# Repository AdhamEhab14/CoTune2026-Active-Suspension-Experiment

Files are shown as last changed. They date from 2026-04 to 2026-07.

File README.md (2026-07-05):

# CoTune Remote Control Lab

A remote-access control systems laboratory built as a graduation project at the Faculty of Engineering, Ain Shams University (Mechatronics Program). CoTune lets a student log in from anywhere, join a queue, tune a real LQR controller, run it on physical hardware over the internet, and watch the result live — combining a mechanical testbed, an embedded real-time controller, and a cloud/web platform into one system.

**Live demo video:** https://www.youtube.com/watch?v=JONjcuDR5eo
**Live platform:** https://main.d35sofljaoe99e.amplifyapp.com/
**Full thesis (PDF):** [`docs/CoTune_Thesis.pdf`](docs/CoTune_Thesis.pdf)

## What's in this repo

This repo brings together the three parts of the CoTune graduation project:

| Folder | What it is |
|---|---|
| [`active-suspension/`](active-suspension/) | Mechanical design, system identification, LQR control, and ESP32/FreeRTOS firmware for the quarter-car active suspension rig. |
| [`rotary-pendulum/`](rotary-pendulum/) | Git submodule pointing to the standalone [Rotary-Inverted-Pendulum](https://github.com/AdhamEhab14/Rotary-Inverted-Pendulum) repo — the Furuta pendulum swing-up + LQR experiment. Kept as its own repo since it also works as a standalone project. |
| [`web-cloud/`](web-cloud/) | The React + AWS front end and cloud infrastructure (IoT Core, Cognito, DynamoDB, Amplify) that puts both experiments online. Built with the team; included here as a snapshot of the work. |
| [`docs/CoTune_Thesis.pdf`](docs/CoTune_Thesis.pdf) | The full graduation thesis this project is based on. |

## Project overview

Traditional control labs are bound by physical presence, fixed schedules, and limited hardware access. CoTune addresses that by exposing two laboratory-scale experiments — an **active suspension system** and a **rotary inverted pendulum** — through a browser-based platform that streams live telemetry and video, and lets students push real control parameters to real hardware.

### 1. Active Suspension

A bench-scale quarter-car rig (sprung mass / unsprung mass / road input, each a plate on linear guides) actuated by a capstan-driven and a lead-screw-driven 775 DC motor.

- **Model:** 2-DOF quarter-car, state vector `[suspension travel, sprung velocity, tire deflection, unsprung velocity]`.
- **System ID:** grey-box estimation of motor and mechanical parameters (`Ks = 900 N/m`, `Bs = 58.08 N·s/m`, `Kus = 1250 N/m`, `Bus = 14.73 N·s/m`) via MATLAB Parameter Estimator, validated in closed loop.
- **Control:** Linear Quadratic Regulator (LQR), gains solved from the Riccati equation, running against a discrete Kalman filter that fuses VL53L0X ToF distance sensors with MPU6050 IMUs.
- **Embedded:** multi-rate FreeRTOS on an ESP32 (500 Hz IMU/control loop, 50 Hz ToF loop), custom C++ S-Function for sensor/Kalman-filter handling, I²C mutex + bus-recovery logic, cascaded alpha/high-pass/low-pass filtering before the control law, PWM/direction output to a Cytron motor driver, and hardware limit-switch safety cutoffs.

### 2. Rotary Inverted Pendulum (standalone submodule)

A Furuta pendulum: a horizontal rotary arm (actuated) balancing a free-swinging vertical pendulum link (unactuated) — a classic underactuated, nonlinear benchmark.

- Nonlinear Euler-Lagrange dynamics, linearized about the upright equilibrium for LQR design.
- Two-stage system identification (motor first, then coupled arm-pendulum dynamics).
- Hybrid embedded controller: energy-based swing-up until the pendulum nears upright, then an automatic switch to LQR stabilization — all running on the same ESP32/FreeRTOS architecture as the suspension rig.
- Lives in its own repo ([Rotary-Inverted-Pendulum](https://github.com/AdhamEhab14/Rotary-Inverted-Pendulum)) and is linked here as a submodule so it can be browsed as part of CoTune as a whole, or used completely on its own.

### 3. Web & Cloud Platform

Turns both rigs into a remote lab, accessible from any browser:

- **Hardware tier:** ESP32 boards run the control loop locally and act as MQTT clients (mutual TLS) to AWS IoT Core.
- **Cloud tier:** AWS IoT Core (MQTT broker), Amazon Cognito (auth), DynamoDB (queue state + session/LQR parameter logging), AWS Amplify (hosting + CI/CD).
- **Client tier:** a modular React SPA — in-browser LQR solver, live Chart.js telemetry, a Twitch-embedded live camera feed, per-experiment access queues with timed sessions, URDF-based 3D pre-experiment simulations, and a Groq/Llama-powered AI assistant scoped to control-theory Q&A.
- MQTT topics separate commands from telemetry per experiment (`SUSP/Parameters` / `suspension/telemetry` at 1 Hz, `ROTARY/Parameters` / `rotary/telemetry` at 10 Hz), QoS 0, JSON payloads under 256 bytes.

### 4. Digital Twin (Active Suspension)

An offline, post-session **seven-state Augmented Extended Kalman Filter (AEKF)** that re-estimates the suspension's real spring stiffness and damping from downloaded session telemetry (augmenting the 4-state model with `Ks`, `Bs`, and a road-phase offset). On a real 140s session it converged to `Ks ≈ 936 N/m` (+4% vs. nominal) and `Bs ≈ 41.2 N·s/m` (-29% vs. nominal), and closed-loop validation against the real data cut amplitude error from 8.2% (nominal model) to 3.1% (AEKF model) — while also surfacing an unmodeled ~1.8 Hz structural resonance in the physical rig. Full derivation and results are in Chapter 6 of the thesis.

## Tech stack

**Mechanical/Electrical:** SolidWorks, Simscape Multibody, 775 DC motors, Cytron motor drivers, VL53L0X ToF sensors, MPU6050 IMUs, incremental encoders.
**Embedded:** ESP32, FreeRTOS, Simulink Support Package for Arduino, custom C++ S-Functions, discrete Kalman filtering.
**Control:** MATLAB/Simulink, LQR, Algebraic Riccati Equation solving, grey-box system identification.
**Cloud/Web:** React 18, AWS Amplify, AWS IoT Core (MQTT), Amazon Cognito, DynamoDB, Chart.js, Three.js/@react-three/fiber + urdf-loader, Groq API (Llama 3.3 70B).

## Team

Graduation project, Mechatronics Engineering Program, Faculty of Engineering – Ain Shams University (2025–2026), supervised by **Dr. Mohamed Omar**.

Adham Ehab Saleh · Abdelrahman Hany Abdelrahman · Ahmed Mohamed Ramadan · Ahmed Yasser Hosny · Khalid Amin Abdullah · Omar Mohamed Fathy

## License

MIT — see [`LICENSE`](LICENSE).

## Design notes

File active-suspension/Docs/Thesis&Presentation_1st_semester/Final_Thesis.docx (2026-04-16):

CoTune Active Suspension & Rotary Inverted Pendulum Submitted By: Adham Ehab Saleh Abdelrahman Hany Abdelrahman Ahmed Mohamed Ramadan Ahmed Yasser Hosny Khalid Amin Abdullah Omar Mohamed Fathy | . Mechatronics Program Graduation Project Report Supervisor: Dr. Mohamed Omar 28/1/2026

DECLARATION

We hereby certify that this Project submitted as part of our partial fulfilment of BSc in Mechatronics Engineering is entirely our own work, that we have exercised reasonable care to ensure its originality, and does not to the best of our knowledge breach any copyrighted materials, and have not been taken from the work of others and to the extent that such work has been cited and acknowledged within the text of our work.

Signed: by

Adham Ehab Saleh Mokhtar
Abdelrahman Hany Abdelrahman Omar
Ahmed Mohamed Ramadan
Ahmed Yasser Hosny
Khaled Amin
Omar Mohamed Fathy Ibrahim

Date: 28th of January 2026

ACKNOWLEDGMENT

We would like to express our sincere gratitude to our supervisor,
Dr. Mohamed Omar, for his guidance and continuous support throughout this project.

Abstract

This thesis focuses on the development of new experimental platforms intended to extend the capabilities of the CoTune Control Laboratory, with the aim of enhancing hands-on learning in control systems education through real-hardware experimentation. The project introduces two laboratory-scale experiments—an active suspension system and a rotary inverted pendulum—designed to complement theoretical coursework with practical implementation and experimental validation.

Both experimental setups were developed from the ground up, starting with mechanical design and hardware integration, followed by system modeling and real-time experimental operation. The platforms are designed to support remote and flexible experimentation, allowing users to configure parameters and observe system behavior through live visual feedback, without requiring physical presence in the laboratory.

The active suspension experiment represents a quarter-car model and enables the study of vertical vehicle dynamics, disturbance effects, and suspension performance using a compact laboratory-scale setup. The rotary inverted pendulum experiment represents a classical unstable system and serves as a benchmark platform for studying nonlinear dynamics, instability, and real-time feedback control.

Together, these experimental platforms expand the range of control problems addressed within the CoTune Laboratory and provide a foundation for future integration into remote-access educational environments, supporting a closer connection between control theory and practical implementation.

Table of Contents

List of Figures

List of Tables

# 1. Introduction

## 1.1. Background

Traditional control laboratories are a core component of engineering education, and most engineering students gain some level of hands-on experience during their studies. However, these laboratories are typically constrained by physical presence, fixed schedules, limited hardware availability, and restricted experiment time. As a result, students are often unable to freely test control theories, explore parameter variations, or repeat experiments outside scheduled lab sessions.

In addition, increasing student numbers and limited laboratory resources make it difficult to provide equal experimental access to all students. These constraints reduce the effectiveness of laboratory-based learning, particularly in control engineering, where repeated experimentation and real-time observation are essential for developing intuition and practical understanding.

The primary limitation addressed in this work is not the absence of control laboratories, but rather the lack of remote, flexible, and continuously accessible experimental platforms that allow students to interact with real hardware without being physically present in the laboratory.

## 1.2. CoTune Laboratory Concept

The Cotune Control Laboratory was developed to overcome the limitations of conventional control labs by enabling remote experimentation on real physical systems. CoTune allows students to access laboratory experiments through an online platform, configure system and controller parameters, and observe real-time system behavior without requiring physical presence in the lab.

Instead of replacing traditional laboratories, CoTune extends their functionality by decoupling experimentation from location and time constraints. This approach allows students to test control theories, analyze system responses, and validate design choices using real hardware, while maintaining the realism and non-ideal behavior of physical systems.

The CoTune Laboratory is designed as a unified framework that integrated multiple experimental platforms, real-time control execution, live data acquisition, and visual feedback, providing consistent user experience across different experiments.

## 1.3. Remote Experimentation and Live Interaction Framework

A core feature of the Cotune Laboratory is the ability to perform experiments remotely without requiring physical presence in the lab. This capability allows students to interact with real experimental setups through an online platform, overcoming common limitations related to lab availability, scheduling, and physical access.

Using the CoTune web interface, students can select an experiment, set the relevant parameters, and run the experiment directly on the physical hardware. The system executes the experiment in real time, while measured signals and system responses are streamed back to the user. In parallel, a live camera feed provides continuous visual feedback, allowing students to observe the physical motion of the system as the experiment is running.

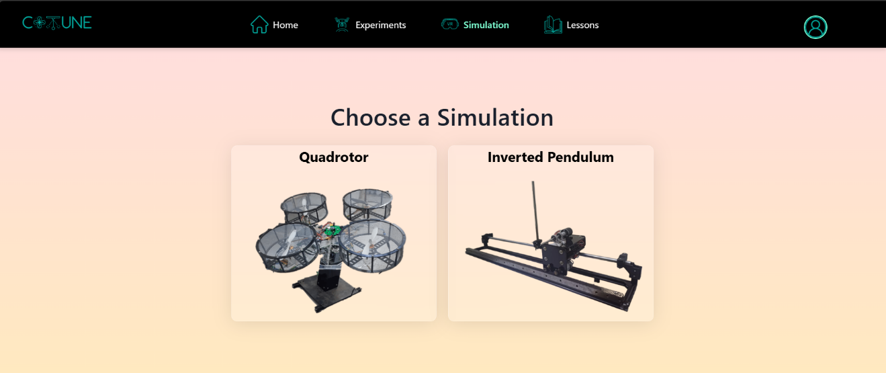
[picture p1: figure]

This interaction model preserves the essential characteristics of hands-on experimentation, including real-time dynamics and non-ideal behavior, while enabling experiments to be performed from any location. Screenshots of the web interface and live camera feed are included to illustrate the structure of the platform and the user interaction flow.

Figure 1.CoTune web Interface

## 1.4. Existing Experimental Platforms

Before the work presented in this thesis, the CoTune Laboratory already included several experimental platforms designed to cover a range of control applications. These platforms include:

- A quadrotor system.
- A linear inverted pendulum
- A ball balancing setup.
- A robotic arm.
- A three-dimensional scanning system.

Each of these experiments addresses different aspects of control systems, such as stability, multivariable control, motion control, and sensor-based feedback. Together, they form a solid foundation for practical control education within the CoTune framework. However, the existing platforms did not fully cover certain important control problems related to disturbance rejection and classical benchmark systems, motivating the addition of new experiments.

## 1.5. Motivation for the Newly Added Experiments

The selection of the active suspension and the rotary inverted pendulum was driven by the need to expand the range of control problems accessible through the CoTune Laboratory. The focus was not on adding more experiments for volume, but on introducing systems that offer clear educational value and complement the existing setups.

Relevance to vehicle dynamics and suitability for studying disturbance effects and performance trade-offs in controlled mechanical systems motivated the choice of the active suspension system. It allows students to directly observe how control actions influence system response under external excitations, making it well suited for both conceptual understanding and practical testing.

Considered a classical unstable system widely used in control education, the rotary inverted pendulum was selected for its ability to clearly demonstrate instability and real-time stabilization. Its dynamics offer an effective platform for testing control strategies under challenging conditions.

Together, these two experiments extend the laboratory’s coverage while fitting naturally within the existing CoTune framework.

# 2. Active Suspension Experiment

## 2.1. Introduction

### 2.1.1. Background

The automotive industry is currently undergoing a significant transformation driven by advances in control systems, electronics and embedded software. Modern vehicles are no longer purely mechanical systems; instead, they are increasingly becoming more complex cyber-physical systems. This evolution has led to higher expectations from passengers, who now demand not only reliable transportation, but also enhanced ride comfort, safety, and overall driving experience.

Among the vehicle subsystems, the suspension system plays a crucial role in isolating the vehicle body from road disturbance while ensuring stable vehicle behavior. Traditional passive suspension systems are limited by fixed mechanical properties that prevent adaptation to varying road conditions. These limitations have motivated the development of advanced suspension technologies that integrate control algorithms with mechanical design.

### 2.1.2. Suspension System

The suspension system is a fundamental subsystem in any road vehicle, responsible for supporting the vehicle weight, isolating the vehicle body from road disturbances, and ensuring stable vehicle behavior during motion by maintaining the traction force between the tire and the road surface.

A typical suspension system consists of mechanical elements such as springs, dampers, and linkages. The springs support the vehicle load and absorb energy from road irregularities, while the dampers dissipate this energy to limit excessive oscillations. Together, these components transfer forces between the vehicle body and the road surface while reducing the unwanted vibrations.

Conventional suspension systems require a compromise between ride comfort and road handling. Improving one usually leads to reduction in the other, which limits the overall system performance.

### 2.1.3. Passive Suspension

Passive suspension is the traditional suspension configuration used in most conventional vehicles. The dynamic behavior of a passive suspension system is entirely determined by the fixed mechanical properties of these components.

Due to the fixed nature of passive suspension parameters, these systems are unable to adapt to changing road conditions or driving situations.

### 2.1.4. Active Suspension

The limitations of the passive suspension have motivated the development of active suspension technology. Addressing this limitation through the integration of mechanical components, sensors, actuators and control algorithms. This actuator can apply controlled forces between the vehicle body and the wheel assembly based on sensor measurements and control commands. Now the system can respond to road disturbance in real time rather than relying solely on passive energy dissipation.

### 2.1.5. Classification of Active Suspension

There are 2 main classes of active suspension

- Semi-Active Suspension

The active element is embedded within the damper to vary the damping coefficient. This is achieved by varying the diameter of an orifice or applying magnetic field to small magnetic particles suspended within the hydraulic fluid in the damper. They are still limited because they can only dissipate energy; they cannot generate an independent force to lift the body or push the wheel down

- Full-Active Suspension

The active element is separate and parallel to the damper to producing force. Such element can be a linear motor or a hydraulic cylinder.

Figure 2. Suspension Types

### 2.1.6. Comparison between Active and Semi-Active Suspension

While Full-Active suspension offers superior performance, the high complexity and large power consumption are obstacles to their adoption into everyday vehicles keeping them as high-end feature offered only in luxury vehicles.

Semi-Active Suspension offers good compromise. Because it has better performance compared to passive systems, and low energy consumption and its simplicity compared to Full-Active suspension made it a more popular option that can be adopted into more vehicles.

### 2.1.7. Problem Statement for Active Suspension

Although active suspension systems are widely used in modern automotive engineering, their practical implementation is rarely emphasized in undergraduate education. Advanced control techniques such as the Linear Quadratic Regulator (LQR) are often studied through simulations, which assume ideal operating conditions and do not capture real-world effects such as friction, actuator limitations, and sensor noise.

As a result, students often struggle to translate theoretical control designs into reliable behavior when applied to real hardware. This challenge is further compounded by the fact that existing active suspension experimental platforms are typically expensive and limited in availability, which restricts meaningful hands-on experience.

This project addresses these limitations by developing a laboratory-scale active suspension experiment that is accessible, cost-effective, and suitable for remote operations. The proposed platform enables the practical validation of control strategies on real hardware while allowing students to directly observe the impact of physical constraints and non-ideal system dynamic.

## 2.2. Mechanical System

### 2.2.1. Overall Mechanical Architecture

The active suspension system is implemented as a bench-scale mechanical representation of a quarter-car model, designed to capture the essential vertical dynamics of a vehicle suspension while maintaining experimental flexibility. Our Mechanical Architecture is inspired by widely used educational active suspension platforms, particularly the Quanser active suspension experiment, which serves as a reference benchmark in control education.

The developed system adopts a vertically stacked, three-mass configuration, where each mass is constrained to move along a single vertical axis. This configuration allows the suspension dynamics to be studied in a simplified yet physically meaningful form, while remaining suitable for laboratory-scale implementation and remote experimentation.

The mechanical structure consists of three rigid plates arranged vertically:

1. Top acrylic plate (sprung mass): represents the vehicle body
2. Middle acrylic plate (unsprung mass): represents the wheel-tire assembly
3. Bottom plate (road input): represents the road surface excitation

Each plate is guided by parallel vertical shafts and supported by linear bearing blocks, ensuring that motion is strictly translated along the vertical axis with negligible lateral displacement

This arrangement allows the system to physically emulate the classical quarter-car suspension model, where:

- Relative displacement between the top and middle plates corresponds to suspension travel
- Relative displacement between the middle and bottom corresponds to tire deflection

### 2.2.2. Actuation system

The actuation system is responsible for actively injecting energy into the suspension mechanism to regulate the vertical motion of the masses and counteract road-induced disturbances. In contrast to passive suspension elements, the actuator enables direct control over the system dynamics.

#### 2.2.2.1. Actuator Type and Placement

A brushed DC motor of type 775 is employed as the active actuator in the suspension system. This motor type was selected due to its high rotational speed, compact form factor, availability, and suitability for laboratory-scale experiments. In an active suspension system, the actuator must react within milliseconds to road bumps. The 775 motor provides the necessary "bandwidth" (speed) to move the plates quickly.

Figure 3. 775 DC motor

Motor Type | Operating Voltage | Nominal Voltage | No-Load Speed | Rated Current | Stall Torque | Weight
775 DC Motor | 6–20 VDC | 12 VDC | 12,000 RPM at 12 V | 1.2 A at 12 V | 79 N.cm at 14.4 V | 350 g

Table 1. 775 DC Motor Specifications

#### 2.2.2.2. Suspension Motor Placement

The actuator is mounted on a rigid bracket that is firmly attached to the top plate (sprung mass). The actuator shaft is directly connected to a pulley, which transfers the motor motion through a belt transmission system with a reduction ratio of 2:1. The second pulley is mounted on a horizontal shaft supported by bearings. Through this configuration, the motor primarily influences the relative motion between the vehicle body (sprung mass) and the wheel assembly (unsprung mass), enabling active regulation of suspension travel and body motion.

Figure 4. Suspension Motor Fixation

#### 2.2.2.3. Road-Excitation Motor Placement

The road excitation motor is mounted on a rigid bracket that is firmly fixed to the base of the system, which serves as the stationary reference frame for the experiment. The motor shaft is connected to a pulley that drives a belt transmission system with a reduction ratio of 2:1. The driven pulley is mounted directly on the lead screw, converting the motor’s rotational motion into linear vertical displacement of the bottom plate. Through this configuration, the motor generates controlled vertical motion of the road input, allowing different excitation profiles to be applied to the suspension system. This arrangement ensures that road disturbances are introduced independently of the suspension actuation, providing a clear and repeatable means of exciting the system for experimental analysis.

Figure 5. Road Excitation Motor Fixation

### 2.2.3. Mechanical Transmission

#### 2.2.3.1. Lead Screw Mechanism for Road Excitation

A lead screw transmission is employed to generate the vertical displacement that represents road excitation. In this mechanism, motor rotation is converted into precise linear motion through a Leadscrew and nut assembly with pitch 8mm per revolution, resulting in a well-defined and repeatable vertical displacement of the base plate.

The lead screw was selected for this function due to its high positional accuracy, mechanical stiffness, and repeatability, which are essential for generating deterministic disturbance profiles such as steps, ramps, or sinusoidal inputs. Ensuring that the imposed input is known and independent of the suspension response.

Figure 6. Lead Screw Mechanism

#### 2.2.3.2. Capstan Mechanism for Active Actuation

The active suspension actuator utilizes a capstan (cable–drum) transmission to convert the rotary motion of the DC motor into a bidirectional linear force applied along the suspension axis. In this configuration, motor rotation drives a cylindrical drum with radius (r = 6mm) around which a tensioned cable is wrapped and routed through guiding elements to the moving suspension plate. Rotation of the drum results in a controlled change in cable length, producing upward or downward linear actuation depending on the direction of rotation.

This mechanism was selected due to its ability to deliver smooth and continuous force transmission with minimal backlash when properly tensioned. The compliant nature of the cable transmission also allows the actuator to interact naturally with the suspension dynamics, making it well suited for applying the active control force between the sprung and unsprung masses.

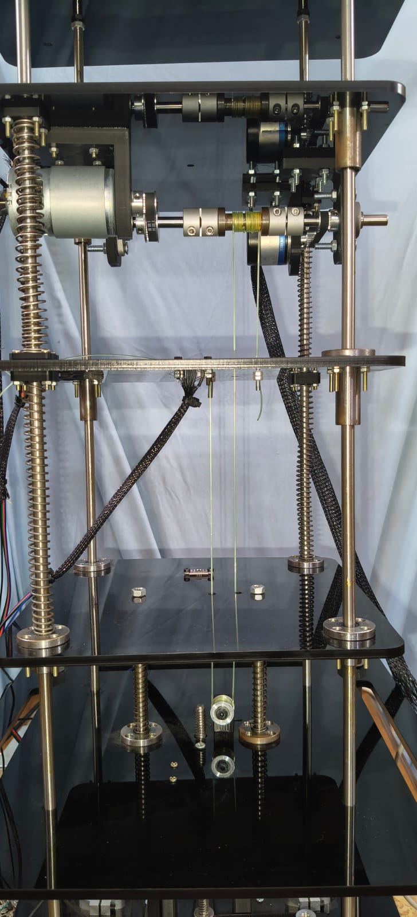
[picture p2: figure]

Figure 7. Cable-Drum

Figure 8. Capstan Mechanism

### 2.2.4. Sensors Selection

The actuation system sensing is essential for the experimental investigation of active suspension dynamics. The sensors used in this experiment provide direct measurements of key physical quantities such as displacement, acceleration, and actuator motion, which are necessary for characterizing system response, validating dynamic models, and enabling closed-loop control implementation.

#### 2.2.4.1. Displacement Measurement

Vertical displacement within the suspension system is measured using two Time-of-Flight (ToF) distance sensors, selected for their non-contact operation and ease of integration.

One ToF sensor is mounted on the bottom plate facing up to measure the relative displacement between the bottom plate and the middle plate, while the second sensor is mounted on the middle plate facing up to measure the relative displacement between the middle plate and the top plate

Enabling evaluation of suspension deflection without relying on mechanical linkages or contact-based sensors. The use of non-contact ToF sensing avoids additional friction or mass loading on the moving components, preserving the natural dynamics of the system.

##### 2.2.4.1.1. Sensor Selection & Specifications

The selected ToF sensor is based on the VL53L0X ranging module developed by STMicroelectronics, which is widely used in precision short-range distance measurement applications.

Parameter | Specification
Measurement range | Up to ~2 m
Resolution | Up to 1 mm
Typical accuracy | ±2 mm
Sampling frequency | Up to 50 Hz
Communication interface | I²C
Operating voltage | 2.8–5 V (via onboard regulation)
Field of view | Narrow (focused optical cone)

Figure 9. TOF Sensor

Table 2. VL53L0X Specifications

The operating principle of a ToF sensor is based on the emission of a modulated infrared light pulse toward a target surface and the subsequent detection of the reflected signal. The sensor measures the time delay between emission and reception, which is proportional to the distance traveled by the light. By internally processing this time delay, the sensor computes the distance to the target with high repeatability over the operating range relevant to the suspension travel.

##### 2.2.4.1.2. Sensor Placement & Measurement Configuration

Two ToF sensors are used in the experimental setup:

- Sensor 1: Mounted on the bottom plate, measuring the vertical displacement of the middle plate (road excitation input)
- Sensor 2: Mounted on the middle plate, measuring the vertical displacement of the top plate (sprung mass motion)

Each sensor is aligned along the vertical axis, with its optical path perpendicular to the target surface.

#### 2.2.4.2. Acceleration Measurement

Accurate measurement of plate acceleration is essential in the active suspension experiment, as acceleration is directly related to ride comfort and is a primary performance metric in suspension control systems. Unlike displacement measurements, which reflect relative motion, acceleration captures the dynamic response of the system to road disturbances and control actions in real time.

For this reason, an inertial measurement unit (IMU) was employed to measure the vertical acceleration of both the middle plate (unsprung mass) and the top plate (sprung mass). These measurements provide direct insight into vibration transmission through the suspension stages and enable quantitative evaluation of controller performance.

##### 2.2.4.2.1. Sensor Selection & Specifications

The MPU6050 was selected as the acceleration sensor for this experiment due to its suitability for laboratory-scale dynamic systems and its balance between performance, cost, and ease of integration. The sensor integrates a 3-axis MEMS accelerometer and a 3-axis gyroscope within a single compact package, allowing synchronized inertial measurements with minimal wiring and computational overhead.

Parameter | Specification
Accelerometer axes | 3 (X, Y, Z)
Measurement range | ±2 g, ±4 g, ±8 g, ±16 g (configurable)
Accelerometer sensitivity | 16,384 LSB/g (±2 g mode)
Sampling frequency | Up to 1 kHz (internal)
Communication interface | I²C
Operating voltage | 3.3 V (5 V tolerant via onboard regulator)
On-chip features | Digital Low-Pass Filter (DLPF), FIFO buffer

Figure 10. MPU6050 Sensor

Table 3. MPU6050 Specifications

For this experiment, the accelerometer was configured to operate in the ±2 g range, maximizing resolution for small-amplitude vertical vibrations typically observed in suspension systems.

##### 2.2.4.2.2. Sensor Placement & Measurement Configuration

Two MPU6050 sensors are used in the system:

- Sensor 1: Mounted on the middle plate to measure the acceleration of the unsprung mass
- Sensor 2: Mounted on the top plate to measure the acceleration of the sprung mass

Both sensors are rigidly attached to their respective plates to ensure accurate transmission of vertical motion. The sensor axes are aligned such that the Z-axis corresponds to the vertical direction of motion, while the remaining axes are ignored in software.

#### 2.2.4.3. Actuator Motion Measurement

Encoder feedback is used in the experimental setup to provide precise information about the rotational motion of the actuators driving the suspension and road excitation mechanisms.

##### 2.2.4.3.1. Sensor Selection & Specifications

Each motor is equipped with a high-resolution incremental encoder with 2400 pulses per revolution (PPR), providing fine angular resolution over the full rotational range.

The encoder provides two quadrature pulse signals that are processed by the control system to extract the following quantities:

- Motor Position: Determined by counting encoder pulses relative to a reference position, providing angular displacement of the motor shaft.

This quantity is directly related to the linear motion of the suspension plates through the mechanical transmission mechanisms (capstan or lead screw), allowing indirect observation of system actuation behavior.

### 2.2.5. Stroke limitation and mechanical Safety

To protect the system from over-travel and mechanical damage, we ensured:

- Defined mechanical stroke limits.
- End-of-travel detection via limit switches

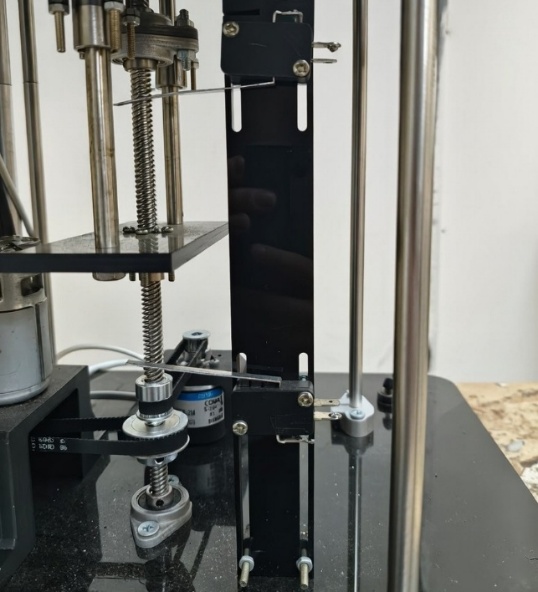
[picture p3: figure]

- Structural clearance to prevent spring over-compression

Figure 11. Limit switches for mechanical safety

### 2.2.6. CAD Modeling and Assembly

The CAD models were developed using SolidWorks and serve as an accurate geometric representation of the finalized mechanical design. The objective of the CAD work is to document the physical realization of the system, verify component integration, and support assembly, alignment, and future modifications.

All mechanical components were modeled individually and subsequently assembled to replicate the real mechanical constraints and degrees of freedom present in the physical system.

#### 2.2.6.1. Full Assembly

The complete CAD assembly of the active suspension system is shown in Figure 12. The model illustrates the stacked plate configuration, guiding columns, and spring–damper elements that define the system’s vertical motion. This view highlights the overall mechanical architecture and the integration of the actuation and excitation subsystems within a rigid and modular frame.

Figure 12. CAD Assembly

#### 2.2.6.2. Capstan mechanism

Figure 13 presents the capstan-based actuation mechanism used for active suspension control. The motor is mounted on a rigid bracket, and its rotational motion is transmitted through a belt-driven capstan arrangement to generate controlled linear force between the upper and middle plates. This configuration ensures smooth force transmission and reduces backlash while maintaining proper shaft alignment.

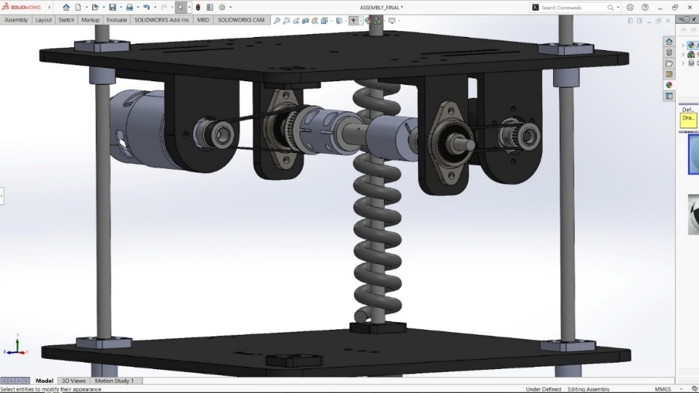
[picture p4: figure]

Figure 13. Capstan Mechanism Assembly

#### 2.2.6.3. Road Excitation Mechanism

The road excitation mechanism is illustrated in Figure 14. A DC motor mounted on the base drives a vertical lead screw through a belt–pulley transmission, producing controlled vertical displacement of the bottom plate. This arrangement allows accurate generation of road disturbance profiles while isolating the motor from axial loading.

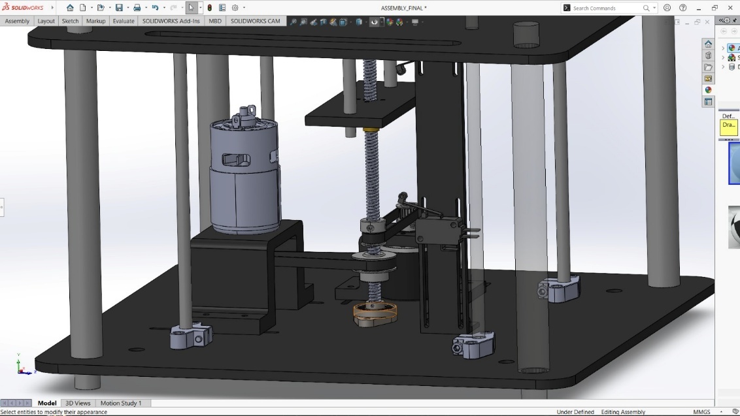
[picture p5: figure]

Figure 14. Road Excitation Mechanism Assembly

## 2.3. Electrical system

### 2.3.1. Electrical System Overview

The electrical system provides the interface between the mechanical plant and the control environment. It is responsible for powering the actuators, interfacing all sensors, and enabling real-time communication between the physical system and the controller. The design emphasizes robustness, compatibility with real-time simulation, and seamless integration with the Simulink-based control framework used throughout the experiment.

All sensing, actuation, and signal processing tasks are implemented exclusively within the Simulink environment, without the use of external microcontroller IDEs. This approach ensures consistency between simulation and experimental implementation and supports the educational objectives of the laboratory.

### 2.3.2. Power Supply and Distribution

The system is powered using a controllable DC power supply with an adjustable output range of 12–24 V, which serves as the main energy source for the experiment. This supply directly feeds the motor drive electronics to meet the high current demands of the DC motors during dynamic operation.

Figure 15. Power Supply

Power distribution is separated into high-power and low-power domains. The high-power path supplies the Cytron motor drivers, which in turn drive the DC motors. Low-power electronics, including the control hardware and sensors, are supplied through a dedicated DC–DC converter that steps down the main supply voltage to a regulated 3.3 V rail suitable for the ESP32 and logic-level devices.

A common ground reference is maintained across all system components to ensure reliable signal integrity, particularly for digital communication interfaces and encoder signals. This separation between power electronics and low-power logic improves system stability and reduces electrical noise coupling.

### 2.3.3. Actuator Drive Electronics

Actuation is achieved using DC motors driven by Cytron motor drivers, which are external to the control hardware. The Cytron drivers were selected due to their ability to withstand high current levels and their minimal voltage drop, ensuring efficient power delivery to the motors. Electrically, motor drivers function as power amplification stages. They accept low-power control signals generated by the controller, such as PWM and direction signals, and convert them into high-current motor drive signals. This configuration isolates the control hardware from the electrical stresses associated with motor operation and ensures safe current handling under varying load conditions.

Figure 16. Cytron MDD10A Motor Driver

### 2.3.4. Wiring and Interconnection Architecture

This section describes the electrical wiring and interconnection architecture of the system, focusing on how power and signal lines are distributed between actuators, sensors, motor drivers, and the control hardware. The objective is to clarify the electrical connectivity at a system level without delving into low-level schematic details.

#### 2.3.4.1. Motor and Driver Connections

Two DC motors are driven through the Cytron motor driver, with each motor connected to a dedicated driver channel. The Cytron driver is powered directly from the controllable 12–24 V DC power supply, enabling it to deliver the required current to both motors under dynamic operating conditions.

Control signals generated by the ESP32 are routed to the Cytron driver inputs, while the high-current motor connections remain isolated from the low-power control circuitry.

#### 2.3.4.2. Encoder Power and Signal Wiring

Two incremental encoders are used for motion measurement. Encoder power (VCC and GND) is supplied directly from the main power supply to meet the encoder operating requirements. The quadrature output signals (Phase A and Phase B) are interfaced with the ESP32 through external 1.2 kΩ pull-up resistors, which pull the signal lines up to 3.3 V.

This configuration ensures compatibility with the ESP32’s logic levels while maintaining reliable signal integrity and accurate quadrature decoding within the Simulink environment.

#### 2.3.4.3. Sensor Interconnection via ESP32 Shield

The inertial sensors (MPU) and time-of-flight (ToF) displacement sensors are mounted and interfaced through an ESP32 PCB shield, which provides organized routing for power and communication lines. All sensors are powered from the regulated 3.3 V rail supplied by the ESP32.

Figure 17. ESP32 shield

Communication between the sensors and the controller is achieved via the I²C bus, with the SDA and SCL lines connected directly to the corresponding ESP32 I²C pins through the shield. This shared bus architecture reduces wiring complexity and supports synchronized data acquisition for all sensors.

#### 2.3.4.4. Control Hardware Power Path

The ESP32 control hardware receives its operating voltage from a DC–DC converter, which steps down the main power supply voltage to a regulated 3.3 V output. This converter is fed directly from the controllable DC power supply, ensuring stable operation of the control hardware and all connected sensors.

A common ground reference is maintained across the power supply, motor drivers, control hardware, and sensors to ensure reliable signal communication and consistent system behavior.

Figure 18. DC-DC Step-Down Converter

#### 2.3.4.5. Wiring Architecture Overview

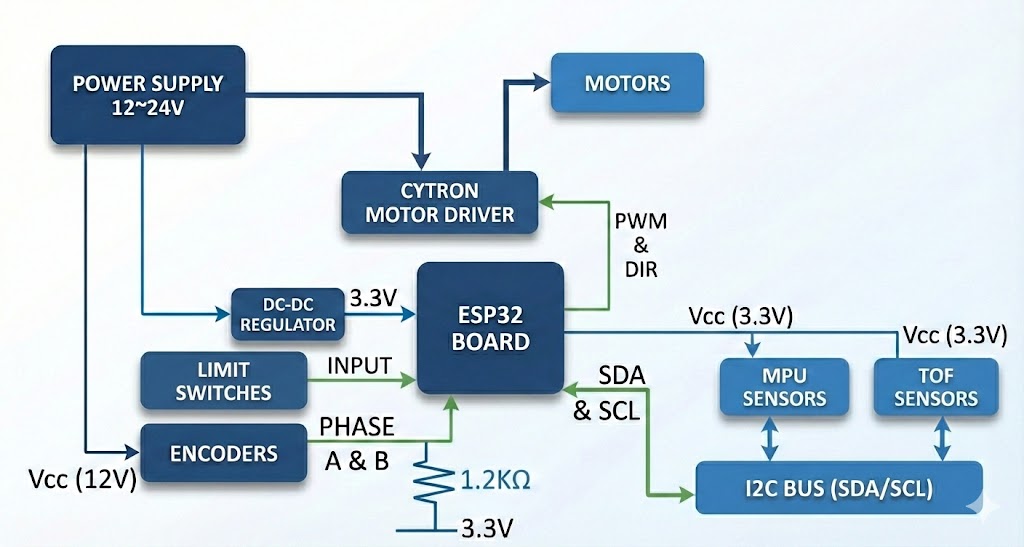
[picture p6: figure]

Figure 19 illustrates the overall wiring and interconnection architecture of the electrical system, showing the distribution of power and signal paths between the power supply, motor drivers, control hardware, actuators, and sensors. The diagram emphasizes the separation between high-current actuation circuits and low-power logic and sensing circuits, while maintaining a unified control structure centered around ESP32.

Figure 19. Wiring Architecture

#### 2.3.4.6. Sensor Interface and Signal Conditioning

All displacement and inertial sensors used in the system are digitally interfaced with the controller through a shared I²C communication bus. This includes the Time-of-Flight (ToF) distance sensors and the inertial measurement units (MPUs), both operating at 3.3 V logic levels and connected to the ESP32 via a dedicated PCB shield that provides power distribution and bus route.

##### 2.3.4.6.1. Multi-Sensor I²C Addressing and Initialization Strategy

Since multiple I²C devices coexist on a single communication bus, special consideration was given to sensor initialization and address management. While the inertial (MPU) sensors support hardware-selectable I²C addresses, the Time-of-Flight (ToF) displacement sensors do not provide a dedicated hardware pin for static address selection. As a result, the simultaneous use of two identical ToF sensors introduces an addressing challenge.

To enable reliable multi-sensor operation, the ToF sensors require a shutdown-based (XSHUT) startup sequence that allows each device to be enabled sequentially and assigned a unique I²C address during system initialization. Implementing this timing-critical and state-dependent sequence using standard Simulink blocks is not ideal.

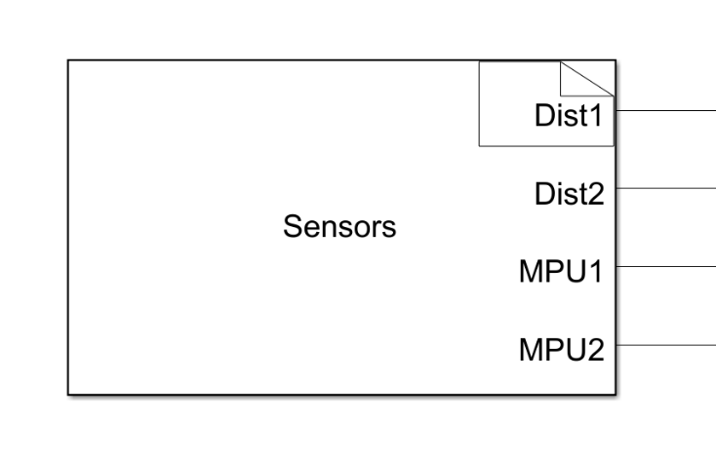
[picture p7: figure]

To overcome this limitation, a custom Simulink S-Function was developed and integrated into the model. This S-Function encapsulates the complete XSHUT control and address reassignment procedure, ensuring deterministic sensor bring-up at startup. Once initialization is completed, normal sensor data acquisition proceeds through standard Simulink blocks.

Figure 20. Sensors S-Function Block

##### 2.3.4.6.2. Signal Filtering

From an electrical perspective, all sensor signals are digital and therefore do not require analog signal conditioning hardware. Instead, signal conditioning is performed entirely within Simulink, where low-pass filtering blocks are applied uniformly to both ToF and IMU measurements to attenuate high-frequency noise prior to control processing. This approach maintains a clean and modular electrical design while allowing signal conditioning parameters to be adjusted directly within the control environment.

## 2.4. Mathematical model & System Identification

### 2.4.1. Dynamic Model

We want to design a control system for an active suspension. We limited our study to a simple 2-DOF quarter car model. We will develop a mathematical model of the quarter car problem that we can use as a basis to understand the vertical movement of the vehicle.

### 2.4.2. Model Parameters

The Model consists of:

- Sprung mass: M_s [Kg]
- Unsprung mass: M_(us) [Kg]
- A suspension spring–damper pair (k_s , B_s ) connecting the sprung mass to the unsprung mass.
- A tire spring–damper pair (k_(us) , B_(us) ) connecting the unsprung mass to the road surface.
- The active suspension control command: F_c applied between the sprung and unsprung masses.
- A road displacement input z_r (t) .

i.e. The generalized coordinates x1 and x2 respectively.

- represents the tire displacement (usnprung mass in quarter car model).
- represents the vehicle body displacement (sprung mass in the quarter car model).

all with respect to the ground. The positive directions are upwards.

Figure 21. Double Mass-Spring-Damper used to model Active Suspension

Assumption:
All displacements are defined with respect to the static equilibrium position of the system.
Consequently, gravitational forces are balanced by spring preload and do not appear in dynamic equations.

### 2.4.3. Equation of Motion

Figure 22. Th Free Body Diagram of M_s

The EOM for M_s will be as follows:

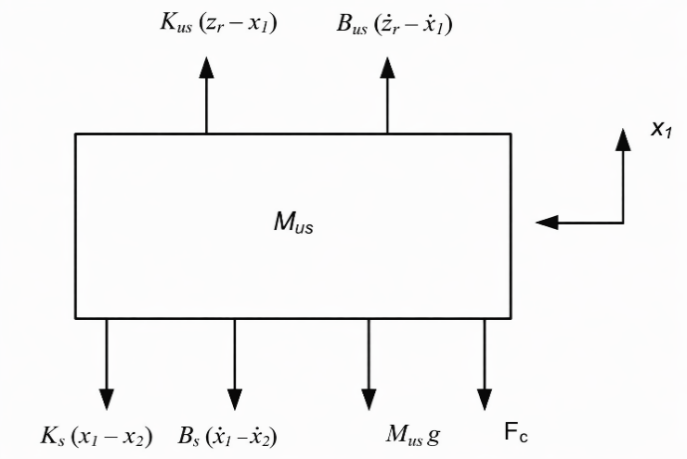
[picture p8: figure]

Figure 23. Th Free Body Diagram of M_(us)

, x_2 =-g+(F_c)/(M_s)+(B_s x_1)/(M_s)-(B_s x_2)/(M_s)+(K_s x_1)/(M_s)-(K_s x_2)/(M_s)#(2.1)

The EOM for M_(us) will be as follows:

, x_1 =-g-(F_c)/(M_(us))-((B_s +B_(us) )x_1)/(M_(us))+(B_s x_2)/(M_(us))+(B_(us) z_r)/(M_(us))-((K_(us) +K_s ) x_1)/(M_(us))+(K_s x_2)/(M_(us))+(K_(us) z_r)/(M_(us))# (2.2)

#### 2.4.3.1. Eliminating Gravity force from EOM

The objective of this section is to prove mathematically that the gravity force only changes the equilibrium points in the Active Suspension EOM, and it does not affect the dynamics of the system.

i.e. x_1 = x_(eq1) , x_2 = x_(eq2)

Substituting these changes in equations 2.1 and 2.2 will give the following results

, M_s g+K_s (x_(eq2) -x_(eq1) )=0#(2.3)

, M_(us) g+K_s (x_(eq1) -x_(eq2) )+K_(us) x_(eq1) =0#(2.4)

As a result, the equilibrium points due to gravity will be:

, x_(eq1) =-(g( M_s +M_(us) ))/(K_(us))#(2.4)

, x_(eq2) =-(g( M_s K_(us) +K_s M_(us) +K_s M_s ))/(K_(us) K_s)#(2.5)

To remove gravity forces from the equations of motion we apply the following change of variables to the equations of motion:

, x_1 =z_(us) -(g( M_s +M_(us) ))/(K_(us))#(2.6)
, x_2 =z_s -(g( M_s K_(us) +K_s M_(us) +K_s M_s ))/(K_(us) K_s)#(2.7)

, x_1 =z_(us) ,x_2 =z_s #(2.8)

, x_1 =z_(us) ,x_2 =z_s #(2.9)

i.e. z_(us) = 0, z_s = 0, will be the equilibrium point of the system.

From Newton’s Second Law:

, ΣF_z =mz#(2.10)

For Sprung Mass:

, M_s z_s +c_s (z_s -z_(us) )+K_s (z_s -z_(us) )=F_c #(2.11)

For Unsprung Mass:

, M_(us) z_(us) +B_s (z_(us) -z_s )+B_(us) (z_(us) -z_r ) + K_s (z_(us) -z_s )+K_(us) (z_(us) -z_r )=-F_c # (2.12)

#### 2.4.3.2. Mapping of Actuator Force

Although the active suspension actuator applies directly to the system, the experimental platform does not provide direct force actuation or measurement. Instead, the system is excited through velocity commands, which are accurately generated and measured.

Starting from (2.12) Expanding the tire damping term yields:

, - B_(us) (z_(us) -z_r )=- B_(us) z_(us) + B_(us) z_r #(2.13)

Substituting (2.12) into (2.13) gives:

, M_(us) z_(us) =-B_s (z_(us) -z_s )- K_s (z_(us) -z_s )-K_(us) (z_(us) -z_r ) - B_(us) z_(us) + B_(us) z_r -F_c #(2.14)

The system is being excited using the road velocity z_r , which generates an equivalent force through the tire damping term. By setting F_c =0 , the equivalent force reduces to:

, F_(eq) = B_(us) z_r #(2.15)

### 2.4.4. State space Model:

#### 2.4.4.1. Definition:

Representing a set of linear differential equations that describe the system's dynamics. The two EOM can be written under the state-space representation as follows:

#### 2.4.4.2. State space Representation

The state space approach is a convenient way to model the quarter-car model with multiple inputs and outputs. The states can be defined as such that they reflect the system performance parameters that have to be optimized as this state space can be later used for state-feedback controller and observer design.

Due to the existence of four energy storage elements in the quarter model; four states for the system.

State Vector:

, X=[x_1 x_2 x_3 x_4 ]=[z_s - z_(us) z_s z_(us) - z_r z_(us) ]#(2.16)

Where,

- x_1 : suspension deflection/travel. (the gap between body and wheel)
- x_2 : vehicle body vertical velocity.
- x_3 : tire deflection which is a measure of road handling. (the gap between wheel and road)
- x_4 : tire vertical velocity.

Input Vector:

, u=[, u_1 , u_2 ]=[, Fc, z_r ]#(2.17)

Where,

- u_1 : Suspension Force
- u_2 : Road excitation velocity.

Output Vector:

, y=[, z_s - z_(us) , z_(us) - z_r ]#(2.18)

Where,

- The first measured output is the suspension travel.
- The Second measured output is the Tire deflection.

Using the EOMs, we can calculate matrices A, B, C, and D as follows:

A =

, [ 0, 1, 0, -1-(K_s)/(M_s), -(B_s)/(M_s), 0, (B_s)/(M_s) 0, 0, 0, 1 (K_s)/(M_(us)), (B_s)/(M_(us)), -(K_(us))/(M_(us)), -((B_s + B_(us) ))/(M_(us))]#(2.19)

, B=[0, 00, 00, -10, (B_(us))/(M_(us))]#(2.20)
, C=[1, 0, 0, 00, 0, 1, 0],D=[, 0 0 , 0 0]#(2.21)

## 2.5. Linear Quadratic Regulator (LQR)

### 2.5.1. Introduction

We know from the previous chapter that Full State Controllability implies that we can arbitrarily place the closed loop poles of the system using suitable feedback matrix equation (4.1).

The intuition may say to place them far into the left half plane. This may sound intuitive, but if we discuss this idea further. We will realize that driving the poles further into Left half plane will result in significantly larger gain Matrix K that will result in unreasonable control signal that can’t be met by the actuator.

Then we need a form of experience to pick a pole location that balances fast response of the system and the limits on actuator signal.

### 2.5.2. LQR Problem Formulation

The LQR formulation defines a cost function J that penalizes both state deviation and control signal. (Q and R) are diagonal weighting matrices

, ∫_0^(∞) X^T Q x+ u^T R u dt#(2.22)

Then we can solve an optimization problem to decide the feedback gains that result in a minimum cost.

The true power of LQR lies in simplicity in tuning because Tuning parameters (The Q and R Matrices) have a meaningful physical interpretation which makes the tuning process far easier and more intuitive.

### 2.5.3. Derivation of Optimal Gain

The solution to the optimization problem is that

u = −Kx

where K = R−1BT S

where S is the solution to the Algebraic Riccati Equation

AT S + SA − SBR−1BT S + Q = 0

Detailed proof for solving the optimization problem and the Riccati Equation can be obtained from many textbooks.

### 2.5.4. LQR Design Process

Now the design process is more systematic. In original pole placement formulation, the process start as follows:

- Decide on Closed Loop pole location
- Obtain Feedback Matrix using Ackermann Formula or comparing the coefficients for low dimensional Systems.

Using the LQR formulation. The process changes to

- Select relative importance of each state and every actuator
- Solve the algebraic Riccati Equation for Feedback matrix

### 2.5.5. LQR and State Estimation

Both pole placement techniques and LQR require the full state vector x to be measured and fed back. This case is rarely realized in actual applications either because it’s not economic to use that many sensors to measure all these states or some state cannot be measured at all.

So, in the actual application we end up with partial measurements of the state vector, and we are required to find a way to reconstruct the full state vector from that measurement.

If the system is Observable, then we can build a state observer (State Estimator) that takes in the incomplete state vector and reconstructs the full state vector to be used in feedback. One such example of state observers is the Kalman Filter which will be discussed in further detail in the following chapter.

The separation of control and observation principle allows to design an optimal state observer (minimizes error) and optimal control (minimizes a cost function) and the combined system of the controller, and the state observer is still optimal which makes the development straightforward. One important combination is the Kalman filter and LQR is called the Linear Quadratic Gaussian (LQG)

## 2.6. Simulation and Results

### 2.6.1. Introduction

This chapter presents the simulation framework and performance evaluation of the active suspension system. The objective of the simulation is to validate the dynamic model of the system and assess the effectiveness of the proposed control strategy under representative road excitation conditions.

The simulation environment is developed using a combination of Simscape and Simulink, where Simscape is employed to model the physical dynamics of the suspension system, while Simulink is used for control implementation, signal processing, and result analysis. This integrated approach ensures consistency between the physical system description and the control-oriented simulation.

The chapter is organized as follows: first, the simulation framework and model architecture are presented, including the plant and controller subsystems. This is followed by the definition of the reference input and control parameters. Finally, simulation results are presented and discussed in terms of key performance metrics such as control effort, suspension travel, road handling, and ride comfort.

### 2.6.2. Simulation Framework Overview

The simulation framework of the active suspension system is developed using an integrated SolidWorks–Simulink–Simscape workflow to ensure strong consistency between the mechanical design and the dynamic model. The CAD model of the system is first created in SolidWorks and then imported into Simulink, where it is used as the basis for constructing the Simscape representation of the mechanical plant.

Simscape is employed to model the physical dynamics of the system using energy-based components that represent masses, springs, and force interactions. Simulink is used to implement the control logic, reference inputs, signal conditioning, and performance evaluation. This integrated approach allows the mechanical structure, physical dynamics, and control system to be developed and evaluated within a unified simulation environment that closely reflects the real experimental setup.

### 2.6.3. Simscape-Based Plant Modeling

The Simscape–Simulink model represents the physical realization of the active suspension system and forms the core of the simulation framework. The mechanical plant is implemented using Simscape components derived from the imported SolidWorks CAD model, ensuring that the simulated dynamics are consistent with the physical geometry and constraints of the system. Simulink is used alongside Simscape to manage signal routing, sensing interfaces, force actuation inputs, and data extraction, resulting in a unified physical–control modeling environment.

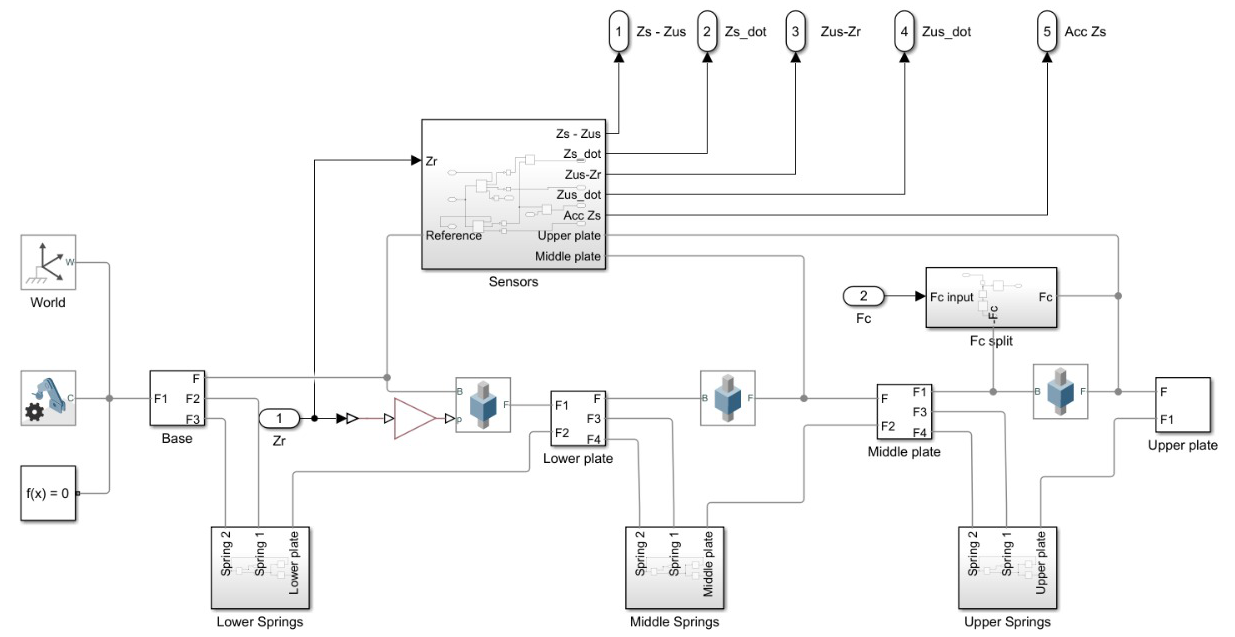
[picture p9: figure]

Figure 24.Simulnk-Simscape

Figure 24 shows the Simscape–Simulink representation of the active suspension system. The model consists of the base, lower plate, middle plate, and upper plate, interconnected through spring elements that represent the suspension stages. Road excitation is applied at the base through the displacement input Z_r , while the active control force F_c is injected into the system and distributed using a force-splitting block. Sensor outputs such as suspension deflection, relative velocities, and sprung-mass acceleration are extracted from the plant and routed to output ports for feedback and performance evaluation.

### 2.6.4. Overall Simulink Model Architecture

The overall Simulink model integrates the physical plant, controller, reference input, and performance evaluation blocks into a complete closed-loop simulation framework. This level of the model emphasizes system-level signal flow and interaction between subsystems rather than internal physical details. The modular structure allows the plant, controller, and reference generation to be developed and tested independently while maintaining a coherent overall architecture.

Figure 25. Simulink Model Architecture

Figure 25 illustrates the overall Simulink architecture of the active suspension system. The reference input block generates the road disturbance signal, which is applied to the plant subsystem. Measured outputs from the plant are fed into the controller block, where the control action is computed and returned to the plant as the active force input F_c . Dedicated output blocks are used to monitor key performance metrics, including suspension travel, road handling, ride comfort, and control effort, enabling direct comparison of system behavior under different operating conditions.

### 2.6.5. Plant Subsystem Description

The plant subsystem represents the complete physical model of the active suspension system and is implemented entirely using Simscape components. It encapsulates the mechanical dynamics derived from the imported CAD model, including the masses, elastic elements, and force interactions that govern system behavior. The subsystem is structured to mirror the physical assembly, ensuring a clear correspondence between simulated components and their real-world counterparts.

Within the plant subsystem, the system is divided into modular elements representing the base, lower plate, middle plate, and upper plate. These elements are interconnected through spring components corresponding to the suspension stages. Road excitation is introduced at the base via the displacement input Z_r , while the active control force F_c is applied through a dedicated force input and distributed internally using a force-splitting mechanism. Sensor interfaces embedded within the plant extract relevant physical quantities such as suspension deflection, relative velocities, and acceleration, which are routed to the controller and output ports for monitoring and evaluation.

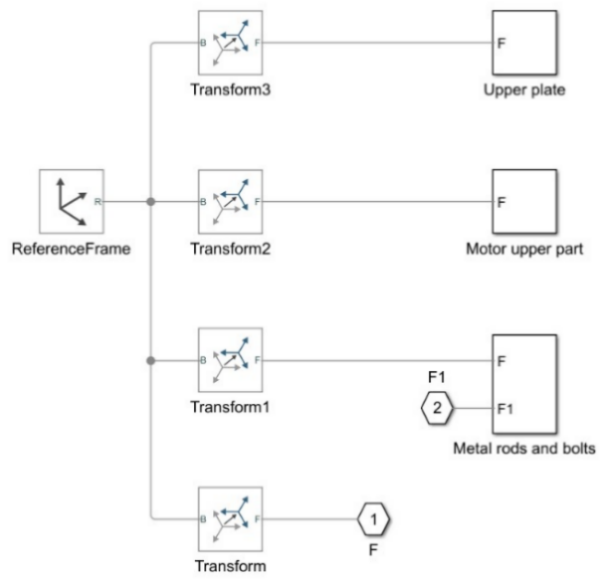
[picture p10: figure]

Figure 26. Upper Plate Subsystem

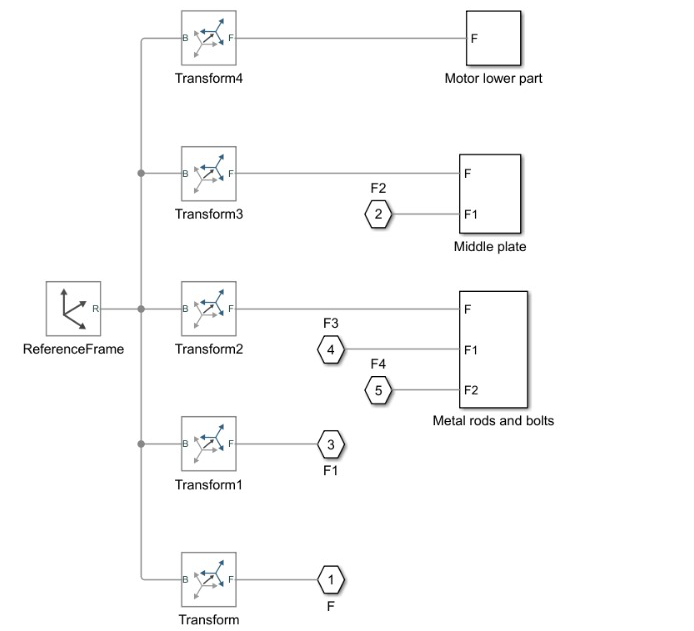
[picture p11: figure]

Figure 27. Middle Plate Subsystem

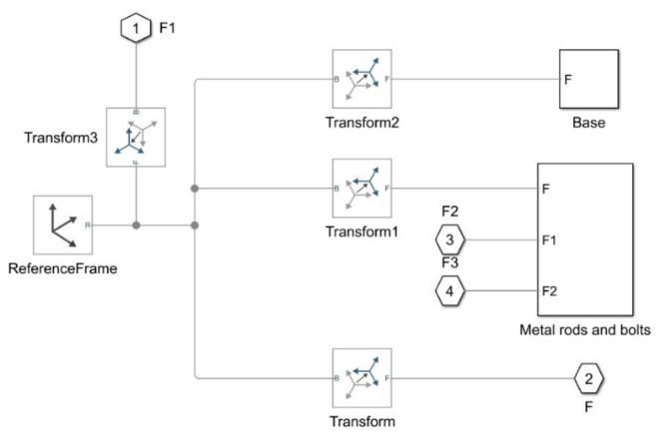
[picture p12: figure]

Figure 28. Lower Plate Subsystem

Figure 30. Sensors Subsystem

Figure 29. Base Subsystem

Figure 31. Springs Subsystem

### 2.6.6. Controller Subsystem Description

The controller subsystem is responsible for generating the active control force applied to the suspension system based on measured system states. It operates within the Simulink environment and interfaces directly with the plant subsystem through defined input and output signals. The controller receives feedback signals representing key dynamic variables of the suspension system and computes the corresponding control action to regulate system behavior.

The control strategy implemented in this work is based on a Linear Quadratic Regulator (LQR) formulation. The controller block processes the measured state variables and outputs a single control force signal F_c , which is applied to the plant as the active actuation input. The controller subsystem is designed as a standalone block, allowing the control law to be modified or replaced without altering the underlying plant model, thereby supporting modularity and extensibility of the simulation framework.

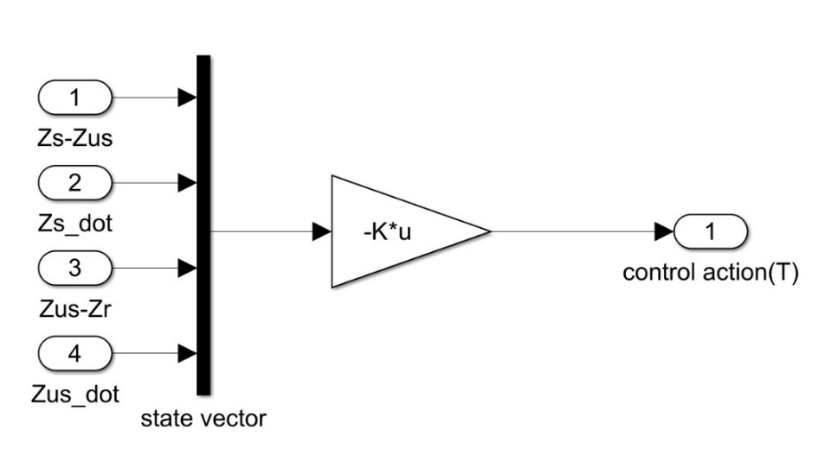
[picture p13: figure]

Figure 32. Controller Subsystem

### 2.6.7. Reference Input and Excitation Profile

The road disturbance applied to the active suspension system is introduced as a vertical displacement input at the base of the model through Z_r . This reference input represents the road excitation used to evaluate the system’s dynamic response under controlled conditions.

The excitation signal is defined as:

- Signal type: Square wave displacement
- Amplitude: 2 cm
- Frequency: 1 Hz

This input profile provides a clear and repeatable disturbance, allowing effective assessment of suspension travel, ride comfort, road handling, and control effort.

### 2.6.8. LQR Design Summary

Item | | Value
System Controllability Rank | 4/4
LQR Gain Matrix K | [11.3848,61.4922, −206.1923, −4.4806]
Closed-Loop Poles | −14.3835±11.8910i, −20.3057±49.0206i

Table 4. LQR gain and closed loop poles

### 2.6.9. Simulation Results and Performance Evaluation

The following results compare the system response under passive and active suspension operation. During the first 5 seconds, the control action is disabled and the system behaves as a passive suspension. At t=5 seconds, the LQR controller is activated, and the system operates in active suspension mode. This transition allows direct comparison of system performance before and after control activation under identical excitation conditions.

#### 2.6.9.1. Control Effort

This plot shows the control force generated by the actuator during the active suspension phase. The control effort is zero during the passive interval and becomes nonzero once the controller is enabled, reflecting the force required to mitigate the applied road disturbance.

Figure 33. Control Effort

#### 2.6.9.2. Suspension Travel

This plot illustrates the relative displacement between the sprung and unsprung masses. Activation of the controller reduces suspension travel magnitude, indicating improved control of suspension deflection compared to the passive case.

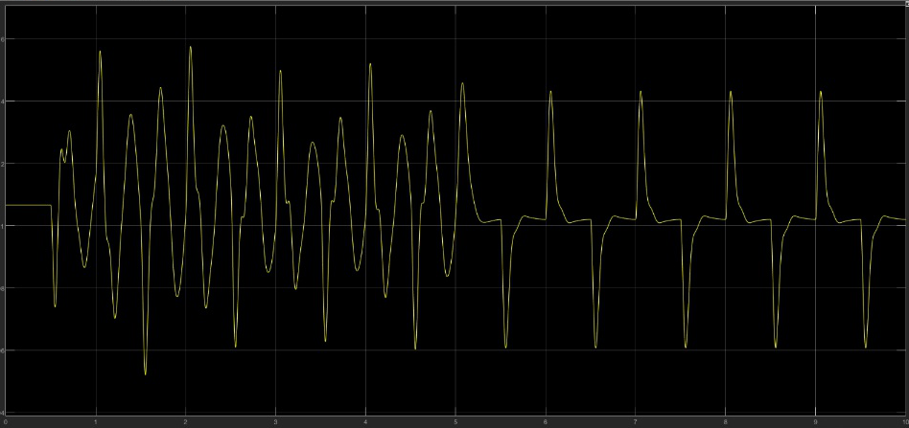
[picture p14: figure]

Figure 34. Suspension Travel

#### 2.6.9.3. Road Handling

This plot represents the ability of the suspension system to maintain tire contact with the road surface. Improved road handling performance is observed after controller activation, as indicated by reduced relative displacement between the wheel and road input.

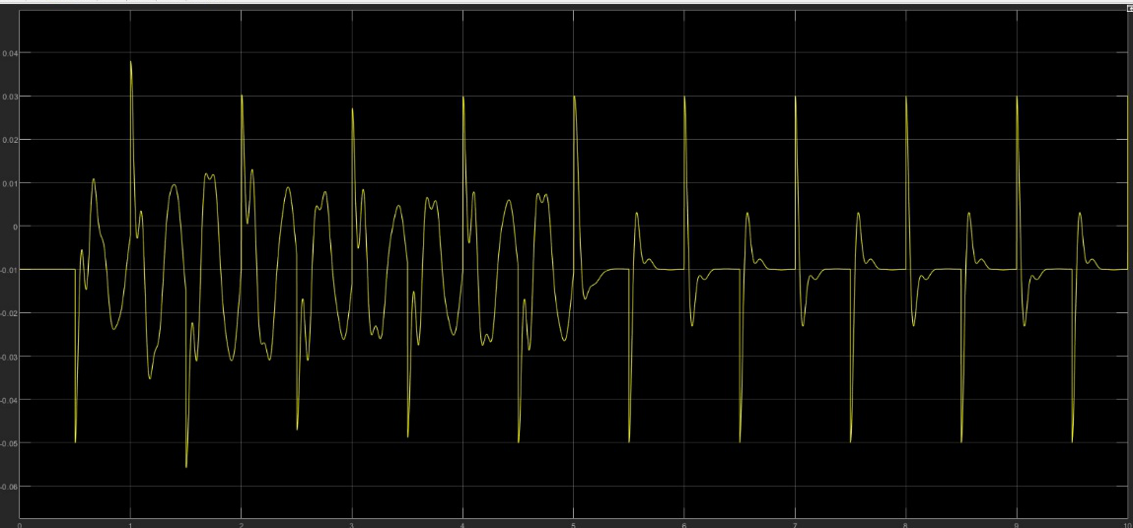
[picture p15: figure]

Figure 35. Road Handling

#### 2.6.9.4. Ride Comfort

This plot shows the vertical acceleration of the sprung mass, which is directly related to passenger comfort. The active suspension significantly attenuates acceleration levels compared to the passive response, demonstrating enhanced ride comfort.

Figure 36. Ride Comfort

## 2.7. Summary

This chapter presented the design and simulation-based evaluation of the active suspension system. The mechanical and electrical architectures were introduced, followed by the development of a physics-based plant model using a SolidWorks–Simulink–Simscape workflow. An LQR controller was implemented on the simulated plant to actively regulate the suspension response under a representative road excitation. Simulation results demonstrated the effectiveness of active control in improving suspension travel, road handling, and ride comfort compared to passive operation, providing a solid foundation for subsequent experimental implementation.

# 3. Rotary Inverted Pendulum

## 3.1. Introduction

### 3.1.1. Background

The Rotary Inverted Pendulum, commonly referred to as the Furuta Pendulum, is a well-established benchmark system in control engineering due to its nonlinear dynamics, underactuated structure, and unstable equilibrium point. The system exhibits strong coupling between rotational degrees of freedom, making it an ideal platform for studying advanced control strategies beyond classical linear control.

The primary motivation for implementing this system is to experimentally validate modern state-space and optimal control techniques under real-time constraints. The pendulum must be stabilized in its upright position while maintaining robustness against external disturbances and actuator limitations. Achieving this objective requires a structured approach that includes physical modeling, controller synthesis, and experimental verification.

### 3.1.2. Rotary Inverted Pendulum

The rotary inverted pendulum system consists of a horizontally rotating arm driven by an electric motor and a pendulum link mounted at the end of the arm, free to rotate in the vertical plane. The motor applies torque to the rotary arm, which indirectly influences the motion of the pendulum through mechanical coupling.

The system has two degrees of freedom:

- The rotary arm angle, which is directly actuated.
- The pendulum angle, which is unactuated and influenced by gravity and inertial forces.

The upright position of the pendulum represents an unstable equilibrium point. Stabilization around this position requires continuous feedback control based on real-time measurements of the system states. Angular position sensors are typically used to measure both the arm and pendulum angles, enabling accurate state estimation and implementation of state-space control strategies.

### 3.1.3. Linear Inverted Pendulum

The linear inverted pendulum system represents an alternative realization of the inverted pendulum problem. In this configuration, the pendulum is mounted on a cart that moves linearly along a horizontal track. The cart motion is actuated, while the pendulum remains unactuated.

Unlike the rotary configuration, the linear inverted pendulum requires a larger physical workspace and is more sensitive to track friction and alignment issues. However, it provides a more intuitive physical interpretation of translational dynamics and is commonly used to introduce inverted pendulum concepts in early control courses.

From a modeling perspective, both systems share similar nonlinear characteristics and unstable equilibrium behavior but differ significantly in their mechanical constraints and actuation mechanisms.

### 3.1.4. Comparison Between Rotary and Linear Inverted pendulum

Although both systems address the same fundamental control problem—stabilizing an unstable equilibrium they differ in mechanical structure and practical implementation.

The rotary inverted pendulum features a compact and mechanically robust design, making it well suited for laboratory environments with limited space. Its rotational actuation minimizes friction-related issues and improves experimental repeatability.

In contrast, the linear inverted pendulum provides more intuitive visualization of translational motion but requires longer tracks and careful mechanical alignment.

From an educational perspective, the rotary inverted pendulum is particularly suitable for advanced control studies, including state-space modeling, pole placement, linear quadratic regulation, and nonlinear swing-up control, while maintaining close agreement with theoretical models.

### 3.1.5. Problem statement for Rotary inverted pendulum

Although inverted pendulum systems are extensively covered in control theory courses, they are often studied only through idealized mathematical models and simulations. Such approaches typically neglect practical non-idealities, including actuator limitations, friction, sensor noise, and unmodeled dynamics, which significantly influence real system behavior.

As a result, students may face difficulty translating theoretical control designs into stable and reliable real-time implementations. The rotary inverted pendulum experiment addresses this gap by providing a physical platform on which theoretical models and control strategies can be experimentally validated. It enables direct observation of nonlinear behavior, instability, and under actuation, thereby reinforcing the connection between analytical design and practical control implementation.

## 3.2. Physical System

### 3.2.1. Overall Mechanical Architecture

The rotary inverted pendulum system is implemented as a compact bench-scale mechanical platform designed to capture the essential dynamics of an unstable, underactuated system. Overall mechanical architecture is inspired by the educational rotary inverted pendulum developed by Quanser, which serves as a reference benchmark in control engineering education.

The system consists of a rigid base structure supporting a horizontally rotating arm driven about a fixed vertical axis. A pendulum link is mounted at the end of the rotary arm through a low-friction revolute joint, allowing it to rotate freely in the vertical plane. This configuration creates two coupled degrees of freedom, with actuation applied only to the rotary arm.

The pendulum mass and geometry are selected such that the upright position represents an unstable equilibrium. The mechanical components are designed to ensure precise alignment, minimal friction, and sufficient structural rigidity, allowing the experimental behavior to closely match the theoretical dynamic model.

### 3.2.2. Actuation system and Placement

A compact 12 V DC geared motor designed for smooth, reliable motion in low-speed applications. Its integrated gearbox provides stable torque output and improved control, making it suitable for robotics, automation setups, and educational projects that require durability and consistent performance.

Figure 37. SG555123000 DC Motor

Motor Type | Operating Voltage | No-Load Speed | Rated Current | Stall Torque | Weight
SG555123000. Motor | 12 VDC | 300 RPM at 12 V | 800 mA at 12 V | 4 N.cm at 12 V | 350 g

Table 5. SG555123000 Motor Specifications

### 3.2.3. Mechanical Transmission

The motor output shaft is connected to a custom coupling element that serves as a rigid mechanical interface. This coupling is bolted to an L-shaped support bracket, forming a stiff transmission path that securely transfers rotational motion while maintaining precise alignment between the motor and the driven assembly.

Figure 38. Rotary Inverted Pendulum

### 3.2.4. Sensors Selection

#### 3.2.4.1. Motor Encoder

The motor is equipped with a high-resolution incremental encoder with 7 pulses per revolution (PPR), providing fine angular resolution over the full rotational range.

The encoder provides two quadrature pulse signals that are processed by the control system to extract the following quantities:

Motor Position: Determined by counting encoder pulses relative to a reference position, providing angular displacement of the motor shaft.

#### 3.2.4.2. Incremental Encoder–Based Pendulum Angle Measurement

The pendulum angular position is measured using a high-resolution incremental encoder with 2400 pulses per revolution (PPR), directly coupled to the pendulum shaft. The encoder generates two quadrature pulse signals, which are processed by the control system to determine the pendulum’s angular displacement over its full range of motion.

The pendulum angle is obtained by counting encoder pulses relative to a defined reference position, enabling precise measurement required for stabilization around the upright equilibrium.

### 3.2.5. CAD Modeling and Assembly

##### 3.2.5.1.1. Full assembly

The rotary inverted pendulum assembly comprises a rigid base frame supporting a DC motor mounted on the upper plate, a horizontally oriented rotary arm, and a vertically hinged pendulum link attached at the arm’s end. The structure is built using stacked plates connected by vertical columns to provide high stiffness and accurate geometric alignment. This compact mechanical arrangement forms a self-contained experimental platform suitable for control system implementation.

Figure 39. CAD Assembly

## 3.3. Mathematical Model and System Identification

### 3.3.1. Dynamic Modeling

The rotary inverted pendulum model considered in this work is illustrated in Figure X. The system consists of a motor-driven rotary arm rigidly coupled to the actuator shaft and rotating in the horizontal plane. The arm has a length L_r , a moment of inertia J_r , and an angular position θ , which is defined to increase positively in the counter-clockwise (CCW) direction. A positive control input results in CCW rotation of the arm.

A rigid pendulum link is mounted at the distal end of the rotary arm and is free to rotate in the vertical plane. The pendulum has a total length L_p , with its center of mass located at a distance l_p from the pivot, and a moment of inertia J_p about its center of mass. The pendulum angle α is defined to be zero when the pendulum is perfectly upright and increases positively for CCW rotation.

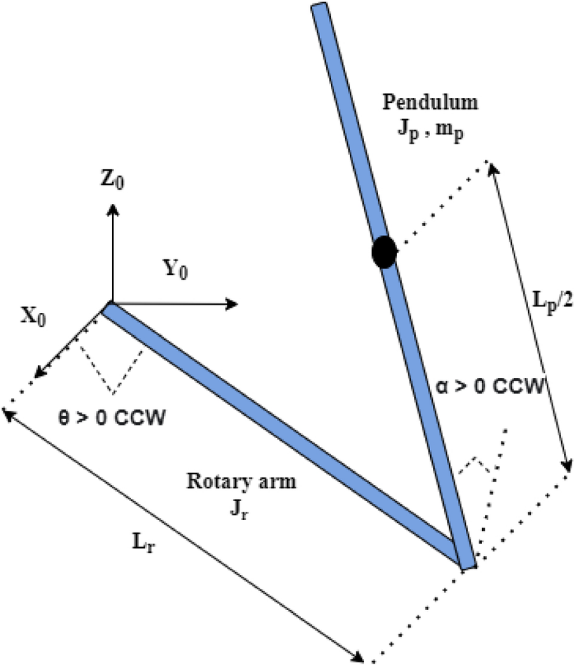
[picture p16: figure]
Free body diagram of rotary inverted pendulum | Download Scientific Diagram

Figure 40. Modeling of Inverted Pendulum

### 3.3.2. Model Parameters

The model consists of:

- L_r : Length of the rotary arm
- L_p : Total length of the pendulum link
- l_p : Distae from pendulum pivot to its center of mass
- m_p : Mass of the pendulum link
- J_r : Moment of inertia of the rotary arm about the vertical axis
- J_p : Moment of inertia of the pendulum about its center of mass
- B_r : Viscous damping coefficient of the rotary arm joint
- B_p : Viscous damping coefficient of the pendulum joint
- g: Gravitational acceleration

### 3.3.3. Equations of Motion

The rotary inverted pendulum consists of an actuated rotary arm and a passive pendulum link mounted at the arm tip. The generalized coordinates are chosen as

, q=[θ, α]^(⊤) #(3.1)

where θ is the rotary arm angle and α is the pendulum angle measured from the upright vertical position. Counter-clockwise rotation is defined as positive for both angles

#### 3.3.3.1. Non-Linear Equations of Motion

The nonlinear equations of motion describe the coupled dynamics between the actuated rotary arm and the passive pendulum link. They are derived using the Euler–Lagrange formulation, where the system’s kinetic and potential energies are expressed in terms of the generalized coordinates θ and α . The resulting equations capture inertial coupling, gravitational effects, and viscous damping, while the rotary arm is driven by a motor-generated torque. These nonlinear dynamics represent the full physical behavior of the system and form the basis for subsequent linearization about the upright equilibrium used for control design.

(m_p L_r^2 +1/4m_p L_p^2 -1/4m_p L_p^2 cos^2 (α)+J_r )θ-(1/2m_p L_p L_r cos(α))α , +(1/2m_p L_p^2 sin(α)cos(α))θα+(1/2m_p L_p L_r sin(α))α^2 =τ-B_r θ#(3.2)

-1/2m_p L_p L_r cos(α)θ+(J_p +1/4m_p L_p^2 )α , -1/4m_p L_p^2 cos(α)sin(α)θ^2 -1/2m_p L_p gsin(α)=-B_p α#(3.3)

#### 3.3.3.2. Motor Torque-voltage Relationship

The motor torque–voltage relationship is incorporated into the rotary arm equation of motion, allowing the system dynamics to be expressed directly in terms of the motor input voltage. This formulation captures the effect of motor back-emf as a velocity-dependent damping term and provides a suitable model for control design.

, τ=(η_g K_g η_m k_t (V_m -K_g k_m θ))/(R_m)#(3.4)

The derived equations follow the standard form of equations of motion, where inertial, damping, and gravitational effects are balanced by the applied torque. , Jx+bx+g(x)=τ_1 #(3.5)

### 3.3.4. Linearized Model and State Space representation

#### 3.3.4.1. Upright Equilibrium Linear Model

The nonlinear equations of motion are linearized about the upright equilibrium configuration of the pendulum. This operating point corresponds to zero angular velocities and small deviations of the pendulum angle from the vertical position, allowing the system to be approximated by a linear time-invariant model suitable for control design.

- Θ = 0
- α = 0
- θ=0
- α=0

Under the small-angle assumption, the trigonometric terms are approximated as sin(α) ≈ α and cos(α) ≈ 1, while higher-order nonlinear terms are neglected. Applying these approximations to the nonlinear equations of motion yields the following linearized equations, which capture the dominant coupled dynamics of the rotary arm and pendulum near the upright position.

, M=[J_r + m_p L_r^2 , -1/2m_p L_p L_r -1/2m_p L_p L_r , J_p +1/4m_p L_p^2 ] #(3.6)

, M[θα]=[τ-B_r θ1/2m_p L_p α-B_p α] #(3.7)

#### 3.3.4.2. Linear State Space Model

The Linear State Space equations are

, x =Ax+Bu #(3.8)

And

, y=Cx+Du #(3.9)

For the linearized rotary inverted pendulum system, the system matrix A and input matrix B are obtained directly from the linearized equations of motion. These matrices describe the coupling between the rotary arm and pendulum dynamics, as well as the influence of the motor input voltage on the system states.

, A=[0, 0, 1, 00, 0, 1, 000, a_32 a_42 , a_33 , a_34 a_43 , a_44 ] #(3.10)

And

, B=[00b_3 b_4 ] #(3.11)

Where

, a_32 =((1/2m_p ^2 L_p ^2 gL_r ))/(∆) #(3.12)

, a_33 =-((J_p +(m_p L_p ^2)/4)B_r)/(∆) #(3.13)

, a_34 = (1/2m_p L_p L_r B_p)/(∆) #(3.14)

, a_42 = ((J_r +(m_p L_r ^2)/4)1/2m_p L_p g)/(∆) #(3.15)

, a_43 = (1/2m_p L_p L_r B_r)/(∆) #(3.16)

, a_44 = ((J_r +(m_p L_r ^2)/4)B_p)/(∆) #(3.17)

, b_3 = (J_p +(m_p L_p ^2)/4)/(∆) #(3.18)

, b_4 = (1/2m_p L_p L_r)/(∆) #(3.19) Where x is the state, u is the control input, A, B, C, and D are state space matrices. For the rotary pendulum system, the state and output are defined

, x^T =[θ α θ α] #(3.20)

And

, y^T =[x_1 x_2 ]#(3.21)

In the output equation, only the position of the motor and link angles are measured. Based on this, the C and D matrices in the output equation are

, C=[1, 0, 0, 00, 1, 0, 0] #(3.23)

And , D=[00] #(3.24)

### 1.1.1. Parameter Estimation

Since the pendulum dynamics are directly influenced by the actuator behavior, the parameter estimation process was structured into two sequential stages. First, the electrical and mechanical parameters of the DC motor were identified independently. These identified motor parameters were then fixed and used in the second stage to estimate the remaining mechanical parameters of the rotary arm–pendulum system.

This staged approach improves identifiability, reduces coupling between parameters, and increases confidence in the resulting model.

#### 3.3.4.3. Motor Parameter Estimation

In the first stage, the DC motor driving the rotary arm was modeled independently from the pendulum dynamics. The objective of this phase was to identify the motor’s electrical and mechanical parameters without the influence of the pendulum load.

The motor model includes the armature electrical dynamics and the rotational mechanical dynamics, accounting for back electromotive force (EMF), torque generation, inertia, and viscous damping. The applied input to the model is the motor voltage, while the measured output is the motor angular speed.

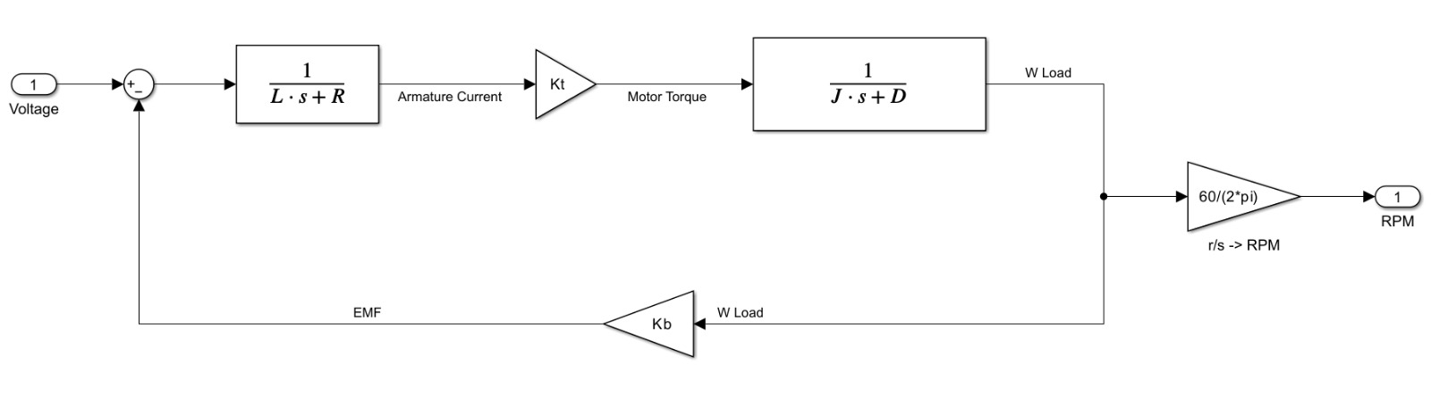
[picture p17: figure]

Figure 41. Motor Model

The parameters estimated in this stage include:

- Armature resistance, R= 3.9336 Ω
- Armature inductance, L = 0.24721 H
- Motor torque constant, Kₜ = 0.39595 N·m/A
- Motor inertia, J = 0.0025202 kg·m²
- Viscous damping coefficient, D = 4.329 × 10⁻⁶ N·m·s/rad

#### 3.3.4.4. System Parameter Estimation

In the second phase, the estimated motor parameters were incorporated into the full rotary inverted pendulum model. The remaining mechanical parameters associated with the rotary arm and pendulum were then identified using the coupled arm–pendulum dynamic equations.

Figure 42. System Linear Model

The parameters estimated in this stage include:

- Rotary arm inertia, Jᵣ = 0.00061423 kg·m²
- Pendulum inertia, Jₐ = 0.00061677 kg·m²
- Rotary arm viscous damping, Bᵣ = 2.2119 × 10⁻⁶ N·m·s/rad
- Pendulum viscous damping, Bₐ = 1.1427 × 10⁻⁶ N·m·s/rad

## 3.4. Simulation and Results

### 3.4.1. Introduction

This chapter presents the simulation framework and performance evaluation of the rotary inverted pendulum system. The primary objective of the simulation is to validate the derived dynamic model, assess the effectiveness of the proposed control strategy, and establish consistency between simulated behavior and experimental results obtained from the physical system.

The simulation environment is developed using Simulink, where the mathematical model of the rotary inverted pendulum is implemented based on the estimated motor and system parameters. The simulation framework supports both open-loop and closed-loop analysis and serves as a foundation for controller design prior to deployment on the physical plant.

### 3.4.2. Simulation Framework Overview

The simulation framework of the rotary inverted pendulum system is developed using an integrated SolidWorks–Simulink–Simscape Multibody workflow to ensure strong consistency between the mechanical design and the dynamic model. The CAD model of the rotary arm and pendulum assembly is first created in SolidWorks and then imported into Simulink using Simscape Multibody, where it forms the basis of the physical plant representation.

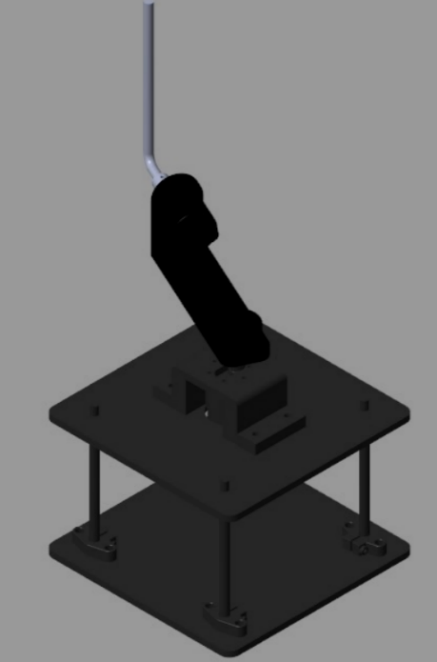
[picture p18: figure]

Figure 43. Sim-mechanics Simulation

Simscape Multibody is used to model the rigid-body dynamics, joints, inertial properties, and kinematic constraints of the pendulum system, while Simulink is employed to implement the control logic, reference inputs, signal conditioning, and performance evaluation. This integrated approach allows the mechanical structure, physical dynamics, and control system of the rotary inverted pendulum to be developed and evaluated within a unified simulation environment that closely reflects the real experimental setup.

### 3.4.3. Overall Simulink Model Architecture

The overall Simulink model integrates the Simscape Multibody–based plant, controller subsystem, reference generation, and monitoring blocks into a closed-loop simulation framework. At this level, the focus is on system-level signal flow and interaction between subsystems rather than internal physical modeling details.

The model is structured to allow independent development and testing of the plant and controller. Measured states from the plant are routed to the controller, which computes the motor input command. System outputs are logged and visualized to evaluate stabilization performance and dynamic response.

#### 3.4.3.1. Hardware In the Loop Model (HIL)

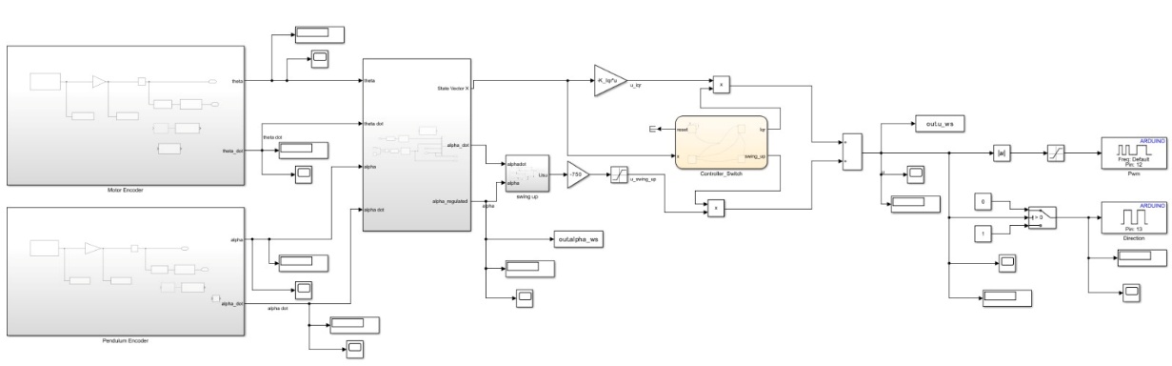
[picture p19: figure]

Figure 43. HIL

#### 3.4.3.2. Model In the Loop Model (MIL)

Figure 44. MIL

### 3.4.4. Plant Subsystem Description

The plant subsystem represents the complete physical model of the rotary inverted pendulum and is implemented using Simscape Multibody components imported from the SolidWorks CAD model. It captures the rigid-body dynamics of the rotary arm and pendulum, including inertial properties, joint constraints, and gravitational effects, while incorporating the estimated motor and mechanical parameters obtained from the parameter estimation stage to ensure accurate representation of the physical system.

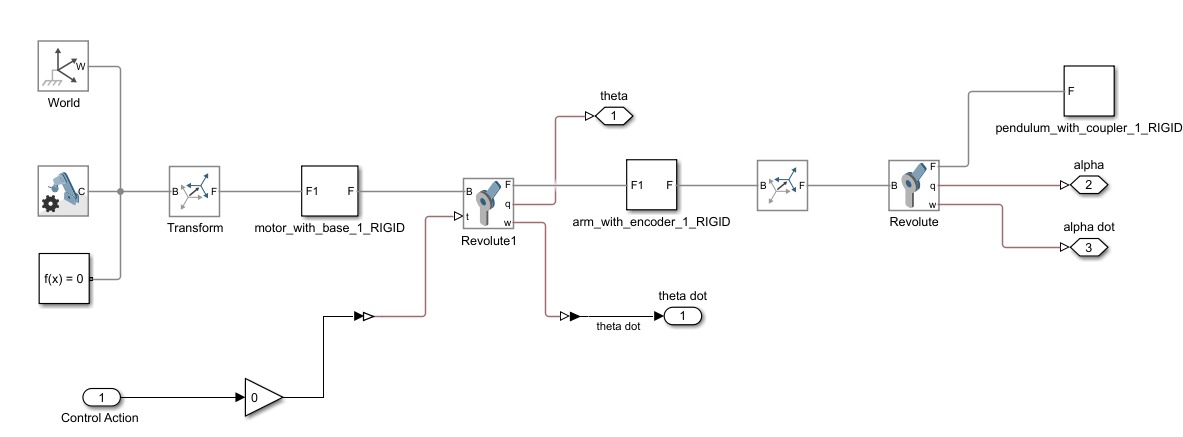
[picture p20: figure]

Figure 45. Plant Subsystem

### 3.4.5. Controllers’ Subsystem Description

The controller subsystem is responsible for driving the pendulum to the upright position and maintaining its stabilization. Two control modes are implemented within Simulink: a swing-up controller and an LQR stabilizing controller. The swing-up controller is initially active and is used to inject energy into the system to bring the pendulum close to the upright configuration. Once the pendulum angle α enters a predefined region around the upright equilibrium, control is smoothly transferred to the LQR controller, which takes over to stabilize the pendulum and regulate the rotary arm motion. This hierarchical control structure ensures reliable transition from large-angle motion to precise stabilization while maintaining a modular design that allows each control strategy to be modified or extended independently.

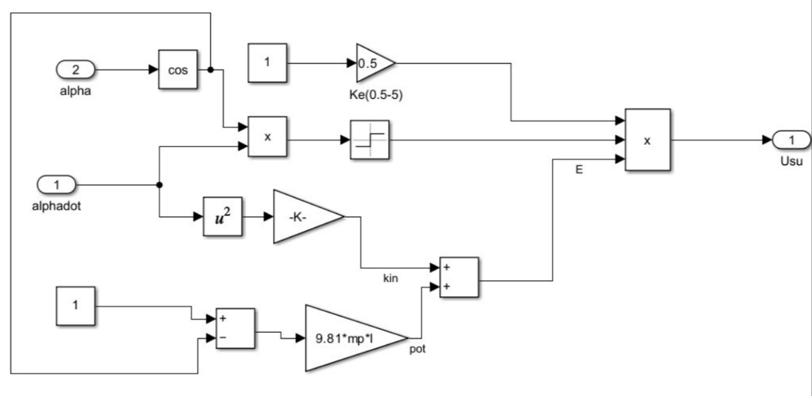
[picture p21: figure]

Figure 47. Swing up control

Figure 46. Controller Subsystem

### 3.4.6. Simulation and Experimental Results

The performance of the rotary inverted pendulum system is evaluated through both simulation and real-time implementation on the physical plant. The system response is assessed using the pendulum angle α , pendulum angular velocity α , rotary arm angle θ , and rotary arm angular velocity θ . The results show successful swing-up and stabilization of the pendulum around the upright equilibrium, with close qualitative agreement between simulated and experimental responses, confirming the validity of the dynamic model and the effectiveness of the implemented control strategy.

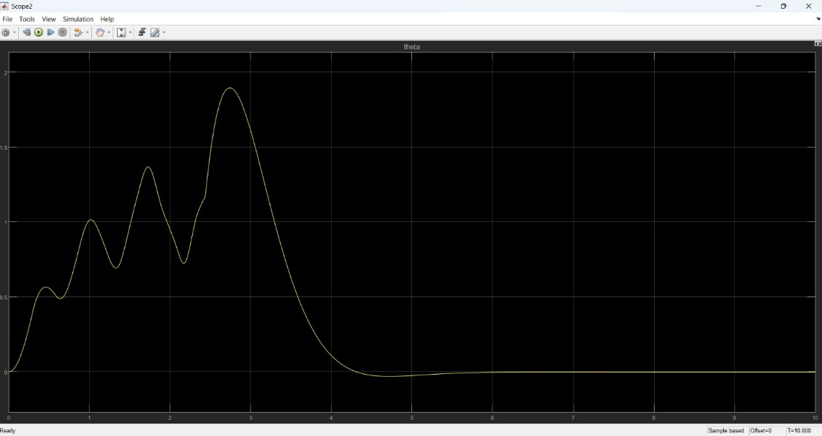
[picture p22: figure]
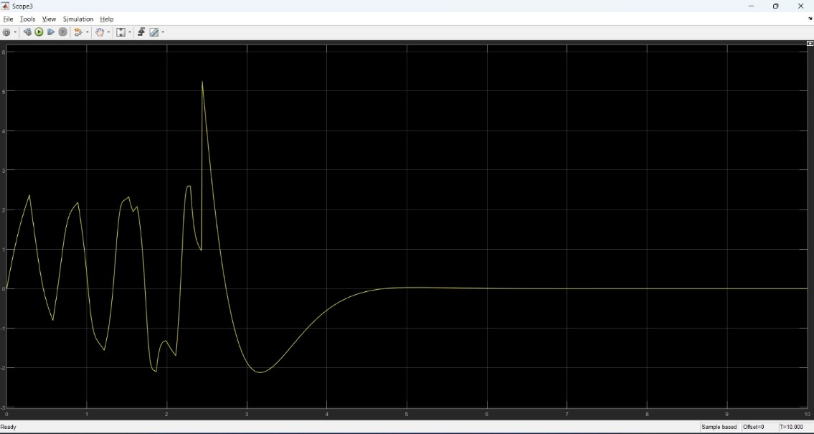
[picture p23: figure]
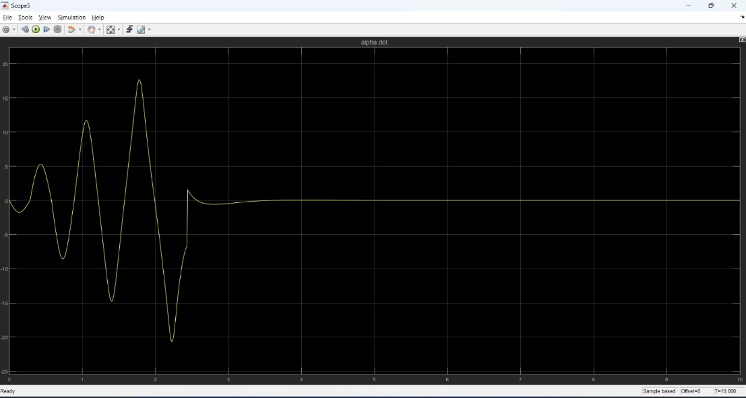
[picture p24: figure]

Figure 48. Simulation Results

# 4. Conclusion

This work presented the design, modeling, control, and evaluation of two control-oriented experimental platforms: an active suspension system and a rotary inverted pendulum. The primary objective was to develop modular, physically realistic systems that support both simulation-based analysis and practical control experimentation within an educational laboratory environment.

For the active suspension system, a complete mechanical and electrical architecture was developed and integrated into a physics-based simulation framework using a SolidWorks–Simulink–Simscape workflow. An LQR controller was designed and evaluated through simulation under representative road excitation. The results demonstrated clear performance improvements with active control compared to passive operation, particularly in terms of reduced suspension travel, improved road handling, and enhanced ride comfort. These results validate the effectiveness of the proposed control strategy and establish readiness for subsequent hardware implementation.

For the rotary inverted pendulum, both the dynamic model and control strategy were implemented and validated in simulation and on the actual physical system. The controller was successfully deployed on the real plant, demonstrating stable real-time operation and confirming the consistency between the simulated model and the experimental behavior. This dual validation highlights the robustness of the modeling approach and the suitability of the pendulum setup as a hands-on platform for studying unstable systems and real-time control.

Overall, this work establishes a coherent framework that bridges mechanical design, electrical integration, simulation, and control implementation. The developed platforms provide a solid foundation for advanced control experimentation, future extensions, and integration into a remote-access laboratory environment.

# 5. Practical Challenges

During the design, integration, and testing of the experimental platforms, several practical challenges were encountered. These challenges are inherent to real-world mechatronic systems and provided valuable insights into the gap between idealized models and physical implementation. This section outlines the main issues observed and the mitigation strategies adopted or planned.

## 5.1. Sensor Noise and Measurement Uncertainty in Active Suspension Sensors

Observed Issue

- High noise levels were observed in sensor measurements, even when the system was in a static equilibrium state.
- This behavior was present in both displacement (ToF) and inertial (IMU) sensors.

Impact on the System

- Noisy and unreliable sensor readings, even at equilibrium, which reduced confidence in the measured states.
- Inconsistent feedback signals, making the measurements unsuitable for direct use in closed-loop control.
- Delay in deploying control on the physical plant, as additional state estimation and filtering were required before safe and reliable control implementation.

Current Handling

- Basic low-pass filtering applied in Simulink to attenuate high-frequency noise.

Planned Mitigation (Next Development Phase)

- Implementation of a Kalman filter–based state estimation framework.
- Sensor fusion to optimally combine noisy measurements with system dynamics.

## 5.2. Capstan Mechanism Tension Loss

Observed Issue:

During rapid downward motion of the suspension system, the capstan string became loose.

This resulted in partial loss of force transmission from the actuator.

Root Cause:

- Slippage between the string and the capstan pulley due to insufficient mechanical engagement.

Impact on the System

- Non-ideal actuator behavior.
- Denying oscillations of the top plate in the open loop mode

Implemented Solution

- A mechanical modification was made by adding a guiding hole in the capstan pulley.
- The string is routed through the hole before fixation to the moving plate, ensuring positive engagement.
- This design change successfully eliminated slippage and restored consistent force transmission.

## 5.3. Low Encoder Resolution in the Rotary Pendulum

Observed Issue:

- The DC motor driving the rotary arm is equipped with an incremental encoder with a very low resolution of 7 pulses per revolution (PPR).

Root Cause:

- The encoder resolution corresponds to an angular resolution of approximately 3° per count, which is insufficient for precise angular feedback in an inverted pendulum system.

Impact on the System:

- Coarse and quantized measurement of the rotary arm angle.
- Inability to accurately detect small angular deviations around the upright equilibrium position.

Planned Mitigation (Next Development Phase)

- Replacing the encoder with a higher-resolution device.

# 6. Future Work and Second Semester Roadmap

The work presented in this thesis establishes a solid foundation for both experimental platforms. The following activities are planned for the second semester to extend the system capabilities, transition from simulation to real-time implementation, and enhance the educational value of the laboratory. The roadmap is organized according to technical dependency and implementation priority.

## 6.1. Sensor Fusion and State Estimation Enhancement

Objective

- Improve measurement reliability and state estimation accuracy for Active Suspension sensors

Planned Work

- Design and implement a Kalman filter–based state estimation framework.
- Fuse displacement and inertial sensor measurements with system dynamics.

Timeline

- Weeks 1–2 of the second semester

## 6.2. Real-Time Control of Deployment on the Active Suspension System

Objective

- Apply the previously designed control strategies to the actual active suspension hardware.

Planned Work

- Deploy control algorithms on the physical plant after sensor noise mitigation.
- Evaluate real-time performance and compare experimental results with simulation.

Dependency

- Completion of sensor fusion and state estimation enhancement.

Timeline

- Week 2 of the second semester

## 6.3. Cloud Networked Model Predictive Control (CNMPC)

Objective

- Extend the control framework by introducing a cloud-executed MPC controller.

Planned Work

- Develop an MPC formulation for the active suspension system.
- Execute control optimization remotely via a the CoTune cloud interface to align with the laboratory vision of remote experimentation

Timeline

- Week 6 of the second semester

## 6.4. Digital Twin Development

Objective

- Create digital twins for both the active suspension system and the rotary inverted pendulum.

Planned Work

- Synchronize real-time experimental data with simulation models.
- Enable live monitoring and system visualization.
- Support remote experimentation and student interaction.

Timeline

- Week 10 of the second semester

## 6.5. Reinforcement Learning (RL) Tutor Module

Objective

- Introduce learning-based control as an educational extension to classical methods.

Planned Work

- Develop an RL-based control tutor for guided experimentation.
- Allow students to compare RL performance with LQR and MPC controllers.
- Integrate the module as an optional advanced learning tool.

Timeline

- Week 12 of the second semester

# 7. References

[1] S. L. Brunton and J. N. Kutz, “Linear Control Theory,” in Data-Driven Science and Engineering: Machine Learning, Dynamical Systems, and Control, Cambridge University Press, Cambridge, UK, pp. 276–320, 2019.

[2] K. Ogata, Modern Control Engineering, 5th ed. Upper Saddle River, NJ, USA: Prentice Hall, 2009.

[3] K. J. Åström and R. M. Murray, Feedback Systems: An Introduction for Scientists and Engineers. Princeton, NJ, USA: Princeton University Press, 2008.

[4] C.-T. Chen, Linear System Theory and Design, 3rd ed. Oxford, UK: Oxford University Press, 1998.

[5] N. S. Nise, Control Systems Engineering, 6th ed. Hoboken, NJ, USA: John Wiley & Sons, 2008.

[6] B. Friedland, Control System Design: An Introduction to State-Space Methods. New York, NY, USA: McGraw-Hill, 1986.

[7] R. Rajamani, Vehicle Dynamics and Control, 2nd ed. New York, NY, USA: Springer, 2012.

[8] MathWorks, “Simscape Multibody User’s Guide,” MathWorks Inc., 2024. [Online]. Available: https://www.mathworks.com

[9] Quanser Inc., “Active Suspension Experiment – Student Workbook,” Quanser Educational Resources. [Online]. Available: https://www.quanser.com

# 8. Appendices

## MATLAB Codes

### Active Suspension LQR Script

%% ACTIVE SUSPENSION CONTROL

% Purpose: Initialize Simscape Data, Build Plant, and Design LQR Controller

clear; clc; close all;

%% 1. INITIALIZATION & DATA LOADING

% Load Simscape mechanical data (Transforms, Masses, etc.)

addpath ActiveSuspension

run(fullfile('ActiveSuspension', 'ACTIVESUSPENSIONSYS_OPT_DataFile.m'))

%% 2. PHYSICAL PARAMETERS (Quanser Nominal)

% Values confirmed from your main and hardware manual

Ms = 1.42; % Sprung mass [kg]

Mus = .580; % Unsprung mass [kg]

Ks = 697; % Suspension stiffness [N/m]

Kus = 1140; % Tire stiffness [N/m]

Bs = 5.0; % Suspension damping [N*s/m]

Bus = 3.6; % Tire damping [N*s/m]

%% 3. STATE-SPACE REPRESENTATION (Force Input)

% States: [z_s-z_us; dz_s; z_us-z_r; dz_us]

A = [ 0 1 0 -1;

-Ks/Ms -Bs/Ms 0 Bs/Ms;

0 0 0 1;

Ks/Mus Bs/Mus -Kus/Mus -(Bs+Bus)/Mus ];

% Control input u = Fc (Active Force in Newtons)

B = [0; 1/Ms; 0; -1/Mus];

%% 4. SYSTEM ANALYSIS (Professional Checks)

% Controllability Check: Must be rank 4

Co = ctrb(A,B);

fprintf('Controllability rank = %d/4\n', rank(Co));

%% 5. LQR DESIGN (Tuning)

% Q matrix: Penalty on states [Travel, Velocity, Deflection, Tire_Vel]

% High values on Q(1,1) and Q(3,3) prioritize stability and ride height.

Q = diag([800, 200, 800, 20]);

% R matrix: Penalty on Force (N). Smaller R = more aggressive control.

R = 0.05;

% Calculate Optimal Gain K

[K, S, E] = lqr(A, B, Q, R);

fprintf('\n--------------------------------------------------\n');

fprintf('LQR Gain K calculated for FORCE input (N):\n');

fprintf('K = [%.4f %.4f %.4f %.4f]\n', K(1), K(2), K(3), K(4));

fprintf('Closed-loop poles:\n');

disp(E);

fprintf('--------------------------------------------------\n');

%% 6. LAUNCH SIMULINK

open(fullfile('ActiveSuspension', 'ACTIVESUSPENSIONSYS.slx'))

fprintf('Simulink model is ready. Set external Gain to 1 to activate LQR.\n');

### Rotary Inverted Pendulum LQR Script

%% Rotary Inverted Pendulum (Upright) - A, B (Vm), and LQR Gain

% State: x = [theta; alpha; theta_dot; alpha_dot]

% Conventions: CCW positive for theta and alpha, alpha = 0 at upright.

clc; clear; close all;

%% Motor Parameters

Rm = 3.9336; % Ohm

kt = 0.39595; % N*m/A

km = 0.39595; % V/(rad/s)

Kg = 1; % Gear ratio

eta_g = 1; % Gear efficiency (already inside kt per your note)

eta_m = 1; % Motor efficiency

%% Physical Parameters

mp = 0.02; % kg

Lp = 0.134; % m (total length)

Lr = 0.185; % m

Jp = 2.9927e-5; % kg*m^2 (about CM)

Jr = 2.852e-3; % kg*m^2

Br = 0.003; % N*m*s/rad

Bp = 0.00005; % N*m*s/rad

g = 9.81; % m/s^2

%% ===== Linearized model about upright (alpha ~ 0) with TORQUE input =====

% From workbook EOM (linearize sin(alpha)~alpha, cos(alpha)~1, drop products)

% M * [theta_ddot; alpha_ddot] = [ tau - Br*theta_dot ;

% +0.5*mp*Lp*g*alpha - Bp*alpha_dot ]

%

% where:

Jr_t = Jr + mp*Lr^2; % effective arm inertia term at alpha=0

Jp_t = Jp + 0.25*mp*Lp^2; % effective pendulum inertia term

Jx = 0.5*mp*Lp*Lr; % coupling term

detM = Jr_t*Jp_t - (Jx^2);

% A,B for torque input u = tau

A_tau = zeros(4,4);

B_tau = zeros(4,1);

A_tau(1,3) = 1;

A_tau(2,4) = 1;

% theta_ddot = (1/detM)*( Jp_t*(tau - Br*theta_dot) + Jx*(0.5*mp*Lp*g*alpha - Bp*alpha_dot) )

A_tau(3,2) = (Jx * (0.5*mp*Lp*g)) / detM; % alpha term

A_tau(3,3) = -(Jp_t * Br) / detM; % theta_dot term

A_tau(3,4) = -(Jx * Bp) / detM; % alpha_dot term

B_tau(3) = (Jp_t) / detM; % tau term

% alpha_ddot = (1/detM)*( Jx*(tau - Br*theta_dot) + Jr_t*(0.5*mp*Lp*g*alpha - Bp*alpha_dot) )

A_tau(4,2) = (Jr_t * (0.5*mp*Lp*g)) / detM; % alpha term

A_tau(4,3) = -(Jx * Br) / detM; % theta_dot term

A_tau(4,4) = -(Jr_t * Bp) / detM; % alpha_dot term

B_tau(4) = (Jx) / detM; % tau term

%% ===== Convert TORQUE input to VOLTAGE input Vm (workbook Eq. 2.4 style) =====

% tau = (eta_g*Kg*eta_m*kt/Rm)*Vm - (eta_g*Kg^2*eta_m*kt*km/Rm)*theta_dot

KtVm = (eta_g*Kg*eta_m*kt)/Rm; % tau per Vm

Kbemf = (eta_g*(Kg^2)*eta_m*kt*km)/Rm; % tau per theta_dot (back-emf term)

A = A_tau;

B = B_tau;

% Add back-emf term into A via the same pattern used in workbook snippet:

A(3,3) = A(3,3) - Kbemf * B(3);

A(4,3) = A(4,3) - Kbemf * B(4);

% Scale B to convert input from tau to Vm:

B = KtVm * B;

% Output matrices (if you need them)

C = [1 0 0 0;

0 1 0 0];

D = [0;0];

%% Display A, B

disp('A (Vm input) ='); disp(A);

disp('B (Vm input) ='); disp(B);

%% ===== LQR design =====

% Tune Q and R as you like (start here, then adjust).

% Q = diag([ 1000, 5000, 2, 50 ]); % [theta, alpha, theta_dot, alpha_dot]

% R = 0.5; % voltage effort penalty

% Q = diag([ 800, 2100, 2, 50 ]); % [theta, alpha, theta_dot, alpha_dot]

% R = 0.25;

%%%%%%% BEST SO FAR %%%%%%%-----------------------------------------------

% Q = diag([ 2000, 8000, 50, 50 ]); % [theta, alpha, theta_dot, alpha_dot]

% R = 1;

% Q = diag([ 2000, 8000, 50, 75 ]); % [theta, alpha, theta_dot, alpha_dot]

% R = 1;

% Q = diag([ 2000, 8000, 50, 100 ]); % [theta, alpha, theta_dot, alpha_dot]

% R = 1;

% Q = diag([ 2000, 12000, 50, 75 ]); % [theta, alpha, theta_dot, alpha_dot]

% R = 1;

%-------------------------------------------------------------------------

Q = diag([ 2000, 12000, 50, 75 ]); % [theta, alpha, theta_dot, alpha_dot]

R = 1;

% MATLAB returns K_lqr for u = -K_lqr*x

K_lqr = lqr(A,B,Q,R);

% If you implement u = K*(xd - x) (Quanser style), use:

K_use = -K_lqr;

disp('K_lqr (for u = -K_lqr*x) ='); disp(K_lqr);

disp('K_use (for u = K_use*(xd - x)) ='); disp(K_use);

% Quick sign check (you wanted [+ - + -] on K_use):

disp('sign(K_use) ='); disp(sign(K_use));

## S-Function Block Code

/* Includes_BEGIN */

#ifndef MATLAB_MEX_FILE

#include <Arduino.h>

#include <Wire.h>

#include "Adafruit_VL53L0X.h"

// -------------------- Addresses --------------------

#define LOX1_ADDRESS 0x30

#define LOX2_ADDRESS 0x31

#define MPU1_ADDRESS 0x68 // AD0=GND

#define MPU2_ADDRESS 0x69 // AD0=3.3V

// -------------------- Shutdown Pins ----------------

#define SHT_LOX1 25

#define SHT_LOX2 26

// -------------------- I2C pins ---------------------

#define I2C_SDA 21

#define I2C_SCL 22

// -------------------- Objects ----------------------

static Adafruit_VL53L0X lox1;

static Adafruit_VL53L0X lox2;

static VL53L0X_RangingMeasurementData_t measure1;

static VL53L0X_RangingMeasurementData_t measure2;

// -------------------- Shared data (ToF) ------------

static volatile int32_t g_dist1_mm = -1;

static volatile int32_t g_dist2_mm = -1;

static volatile uint32_t g_tof_t_us = 0; // timestamp of last ToF update (micros)

static volatile bool g_lox1_ok = false;

static volatile bool g_lox2_ok = false;

// Critical section for shared variables (not I2C!)

static portMUX_TYPE g_dataMux = portMUX_INITIALIZER_UNLOCKED;

// -------------------- I2C Mutex (THE IMPORTANT FIX)-

static SemaphoreHandle_t g_i2cMutex = NULL;

// -------------------- Helpers ----------------------

static inline bool I2C_Lock(TickType_t timeoutTicks)

{

if (!g_i2cMutex) return true; // fallback (shouldn't happen)

return (xSemaphoreTake(g_i2cMutex, timeoutTicks) == pdTRUE);

}

static inline void I2C_Unlock()

{

if (g_i2cMutex) xSemaphoreGive(g_i2cMutex);

}

static inline void i2cWriteByte(uint8_t addr, uint8_t reg, uint8_t val)

{

Wire.beginTransmission(addr);

Wire.write(reg);

Wire.write(val);

Wire.endTransmission(true);

}

static inline bool i2cReadBytes(uint8_t addr, uint8_t startReg, uint8_t *buf, size_t len)

{

Wire.beginTransmission(addr);

Wire.write(startReg);

if (Wire.endTransmission(false) != 0) return false; // repeated start

int got = Wire.requestFrom((int)addr, (int)len, (int)true);

if (got != (int)len) return false;

for (size_t i = 0; i < len; i++) buf[i] = Wire.read();

return true;

}

static inline void wakeUpMPU(uint8_t address)

{

// PWR_MGMT_1 = 0 -> wake

i2cWriteByte(address, 0x6B, 0x00);

}

static inline void configMPU6050(uint8_t address)

{

// Baseline config for control/estimation:

// DLPF ~ 42 Hz, Fs = 200 Hz, Accel ±4g, Gyro ±500 dps.

wakeUpMPU(address);

delay(2);

// CONFIG (0x1A) DLPF_CFG=3 -> ~42 Hz

i2cWriteByte(address, 0x1A, 0x03);

// SMPLRT_DIV (0x19) = 4 -> 1000/(1+4)=200 Hz (when DLPF enabled)

i2cWriteByte(address, 0x19, 0x04);

// ACCEL_CONFIG (0x1C) AFS_SEL=1 -> ±4g

i2cWriteByte(address, 0x1C, 0x08);

// GYRO_CONFIG (0x1B) FS_SEL=1 -> ±500 dps

i2cWriteByte(address, 0x1B, 0x08);

}

static inline bool readMPUAccelXYZ(uint8_t address, int16_t &ax, int16_t &ay, int16_t &az)

{

uint8_t buf[6];

if (!i2cReadBytes(address, 0x3B, buf, 6)) return false;

ax = (int16_t)((buf[0] << 8) | buf[1]);

ay = (int16_t)((buf[2] << 8) | buf[3]);

az = (int16_t)((buf[4] << 8) | buf[5]);

return true;

}

// ------------- VL53L0X address assignment -----------

static void setVL53IDs()

{

// Reset both

digitalWrite(SHT_LOX1, LOW);

digitalWrite(SHT_LOX2, LOW);

delay(10);

// Bring both high

digitalWrite(SHT_LOX1, HIGH);

digitalWrite(SHT_LOX2, HIGH);

delay(10);

// Keep #1 awake, #2 shut down

digitalWrite(SHT_LOX1, HIGH);

digitalWrite(SHT_LOX2, LOW);

delay(10);

// IMPORTANT: protect I2C during begin()

if (I2C_Lock(pdMS_TO_TICKS(50))) {

g_lox1_ok = lox1.begin(LOX1_ADDRESS, false); // false: don't restart Wire

I2C_Unlock();

} else {

g_lox1_ok = false;

}

delay(10);

// Now wake #2

digitalWrite(SHT_LOX2, HIGH);

delay(10);

if (I2C_Lock(pdMS_TO_TICKS(50))) {

g_lox2_ok = lox2.begin(LOX2_ADDRESS, false);

I2C_Unlock();

} else {

g_lox2_ok = false;

}

delay(10);

}

// ------------- ToF background task ------------------

static void ToFTask(void *param)

{

// Run ToF at a realistic rate. 20 ms -> 50 Hz.

const TickType_t period = pdMS_TO_TICKS(20);

TickType_t lastWake = xTaskGetTickCount();

for (;;)

{

vTaskDelayUntil(&lastWake, period);

int32_t d1 = -1, d2 = -1;

// Lock the I2C bus for the whole ToF transaction

if (!I2C_Lock(pdMS_TO_TICKS(30))) {

// Couldn't get the bus quickly; skip this cycle (do not block control loop)

continue;

}

if (g_lox1_ok) {

lox1.rangingTest(&measure1, false);

if (measure1.RangeStatus != 4) d1 = (int32_t)measure1.RangeMilliMeter;

}

if (g_lox2_ok) {

lox2.rangingTest(&measure2, false);

if (measure2.RangeStatus != 4) d2 = (int32_t)measure2.RangeMilliMeter;

}

I2C_Unlock();

portENTER_CRITICAL(&g_dataMux);

g_dist1_mm = d1;

g_dist2_mm = d2;

g_tof_t_us = micros();

portEXIT_CRITICAL(&g_dataMux);

}

}

#endif

/* Includes_END */

/* Externs_BEGIN */

/* extern double func(double a); */

/* Externs_END */

void Sensors_Start_wrapper(void)

{

/* Start_BEGIN */

#ifndef MATLAB_MEX_FILE

pinMode(SHT_LOX1, OUTPUT);

pinMode(SHT_LOX2, OUTPUT);

// Create I2C mutex FIRST

g_i2cMutex = xSemaphoreCreateMutex();

// I2C init once

Wire.begin(I2C_SDA, I2C_SCL);

Wire.setClock(400000); // 400 kHz

delay(20);

// Configure MPUs (protected)

if (I2C_Lock(pdMS_TO_TICKS(50))) {

configMPU6050(MPU1_ADDRESS);

delay(5);

configMPU6050(MPU2_ADDRESS);

I2C_Unlock();

}

delay(5);

// Setup ToFs with unique addresses

setVL53IDs();

// Initialize shared values

portENTER_CRITICAL(&g_dataMux);

g_dist1_mm = -1;

g_dist2_mm = -1;

g_tof_t_us = micros();

portEXIT_CRITICAL(&g_dataMux);

// Start ToF task (core 0)

xTaskCreatePinnedToCore(ToFTask, "ToFTask", 4096, NULL, 1, NULL, 0);

#endif

/* Start_END */

}

void Sensors_Outputs_wrapper(int32_T *Dist1,

int32_T *Dist2,

int16_T *MPU1,

int16_T *MPU2)

{

/* Output_BEGIN */

#ifndef MATLAB_MEX_FILE

// -------- 1) Read MPUs at Ts (your synchronized tick) --------

int16_t ax1=0, ay1=0, az1=0;

int16_t ax2=0, ay2=0, az2=0;

bool ok1 = false, ok2 = false;

// Lock I2C briefly for MPU reads

if (I2C_Lock(pdMS_TO_TICKS(5))) {

ok1 = readMPUAccelXYZ(MPU1_ADDRESS, ax1, ay1, az1);

ok2 = readMPUAccelXYZ(MPU2_ADDRESS, ax2, ay2, az2);

I2C_Unlock();

}

if (!ok1) {

// Sentinel for "bad read"

ax1 = ay1 = az1 = (int16_t)0x8000;

// Try to re-wake (protected)

if (I2C_Lock(pdMS_TO_TICKS(5))) { wakeUpMPU(MPU1_ADDRESS); I2C_Unlock(); }

}

if (!ok2) {

ax2 = ay2 = az2 = (int16_t)0x8000;

if (I2C_Lock(pdMS_TO_TICKS(5))) { wakeUpMPU(MPU2_ADDRESS); I2C_Unlock(); }

}

// NOTE: MPU1 and MPU2 ports MUST be dimensioned [3x1] in S-Function Builder

MPU1[0] = ax1; MPU1[1] = ay1; MPU1[2] = az1;

MPU2[0] = ax2; MPU2[1] = ay2; MPU2[2] = az2;

// -------- 2) Sample-and-hold latest ToF (no blocking) --------

int32_t d1, d2;

portENTER_CRITICAL(&g_dataMux);

d1 = g_dist1_mm;

d2 = g_dist2_mm;

portEXIT_CRITICAL(&g_dataMux);

Dist1[0] = d1;

Dist2[0] = d2;

#endif

/* Output_END */

}

void Sensors_Terminate_wrapper(void)

{

/* Terminate_BEGIN */

/*

* Custom Terminate code goes here.

*/

/* Terminate_END */

}

Faculty of Engineering Ain Shams University Mechatronics Engineering Program

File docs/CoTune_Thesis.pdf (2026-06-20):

## Mechatronics Engineering Department

## CoTune Lab

# Active Suspension & Rotary Inverted Pendulum

## Graduation Project Thesis

Submitted in fulfillment of the requirements for the B.Sc. degree in Mechatronics Engineering

Team Members:
Name | ID
Adham Ehab Saleh | 2100679
Abdelrahman Hany Abdelrahman 2100359
Ahmed Mohamed Ramadan | 2100323
Ahmed Yasser Hosny | 2101101
Khalid Amin Abdullah | 2100808
Omar Mohamed Fathy | 2100503

Supervisors:

Dr. Mohamed Omar

Academic Year: 2025–2026

1 Elsarayat St., Abbaseya, 11517 Cairo, Egypt Fax: (+20 2) 26850617
www.eng.asu.edu.eg

i

## DECLARATION

We hereby certify that this Project submitted as part of our partial fulfilment of BSc in

Mechatronics Engineering is entirely our own work, that we have exercised reasonable care to

ensure its originality, and does not to the best of our knowledge breach any copyrighted

materials, and have not been taken from the work of others and to the extent that such work has

been cited and acknowledged within the text of our work.

Signed by:

Date: 20th of June 2026

Adham Ehab Saleh

Abdelrahman Hany Abdelrahman

Ahmed Mohamed Ramadan

Ahmed Yasser Hosny

Khaled Amin

Omar Mohamed Fathy

ii

## ACKNOWLEDGMENT

It is with genuine appreciation that we acknowledge the invaluable contributions of those who

made this graduation project possible. First and foremost, we would like to express our profound

gratitude to our project supervisor, Dr. Mohamed Omar. His continuous support, visionary

guidance, and deep expertise provided the foundation for our work. His patience and

encouragement kept us motivated, and his constructive feedback was vital to the successful

completion of this research.

Furthermore, we owe a special debt of gratitude to Eng. Mohab Ahmed and Eng. Abdullah

Awadullah. We cannot thank them enough for their constant help, practical insights, and hands-

on assistance during the implementation phases. Their dedication to helping us navigate complex

technical hurdles was a critical factor in bringing this project to life.

iii

## ABSTRACT

This thesis focuses on the development of new experimental platforms intended to extend the

capabilities of the CoTune Control Laboratory, with the aim of enhancing hands-on learning in

control systems education through real-hardware experimentation. The project introduces two

laboratory-scale experiments—an active suspension system and a rotary inverted pendulum—

designed to complement theoretical coursework with practical implementation and

experimental validation. Both experimental setups were developed from the ground up,

starting with mechanical design and hardware integration, followed by system modeling and

real-time experimental operation. The platforms are designed to support remote and flexible

experimentation, allowing users to configure parameters and observe system behavior through

live visual feedback, without requiring physical presence in the laboratory.

The active suspension experiment represents a quarter-car model and enables the study of

vertical vehicle dynamics, disturbance effects, and suspension performance using a compact

laboratory-scale setup. The rotary inverted pendulum experiment represents a classical
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

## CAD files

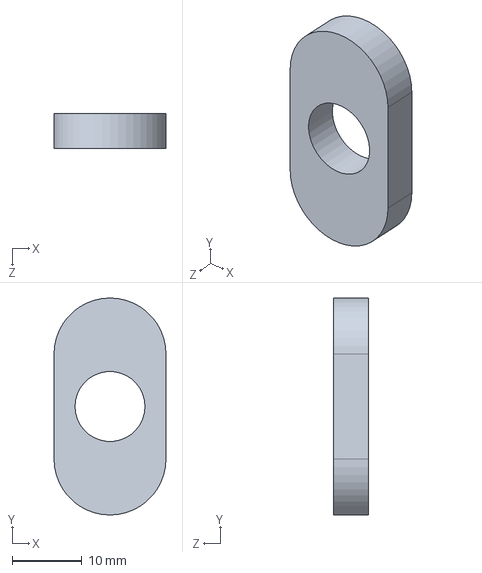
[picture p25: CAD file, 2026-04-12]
active-suspension/ActiveSuspension_kh/ActiveSuspension/Solidworks/maintien.SLDPRT
16.0 x 31.0 x 5.00 mm

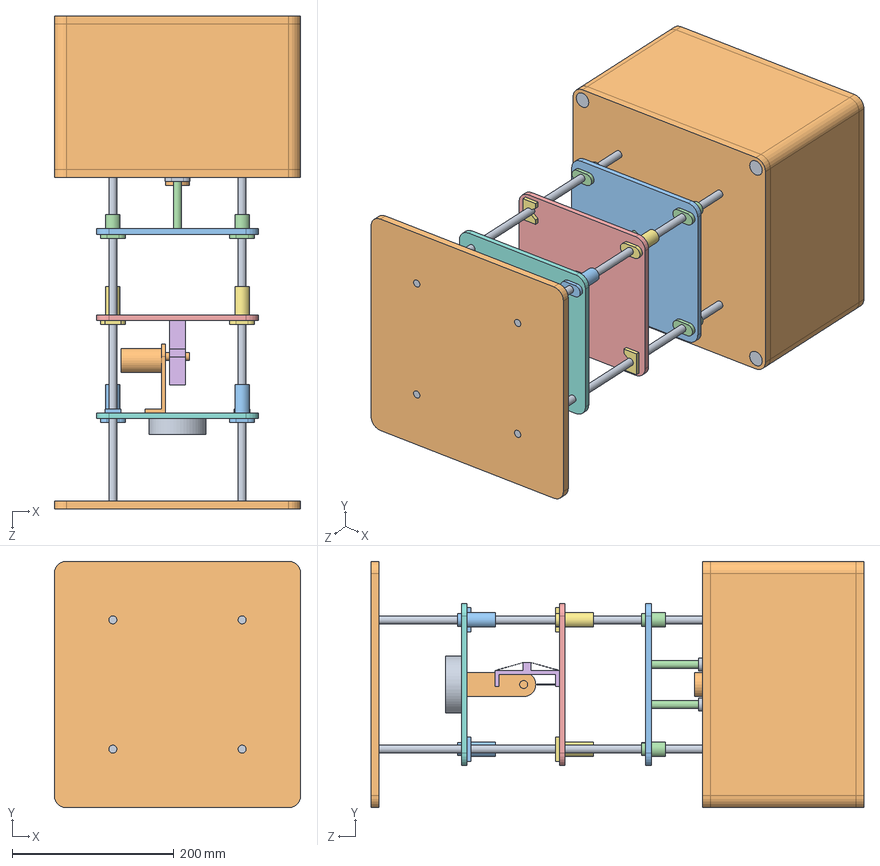
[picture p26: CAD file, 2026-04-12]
active-suspension/ActiveSuspension_kh/ActiveSuspension/Solidworks/ACTIVESUSPENSIONSYS_OPT.SLDASM
305.0 x 305.0 x 610.0 mm
barres_opt
base_opt
PLATEMillieubas
barre_plate_bas
PLATEMillieu
moteur_bas
barres_plate_millieu
PLATEMillieuHaut
Poid
moteur_haut
barres_plate_haut

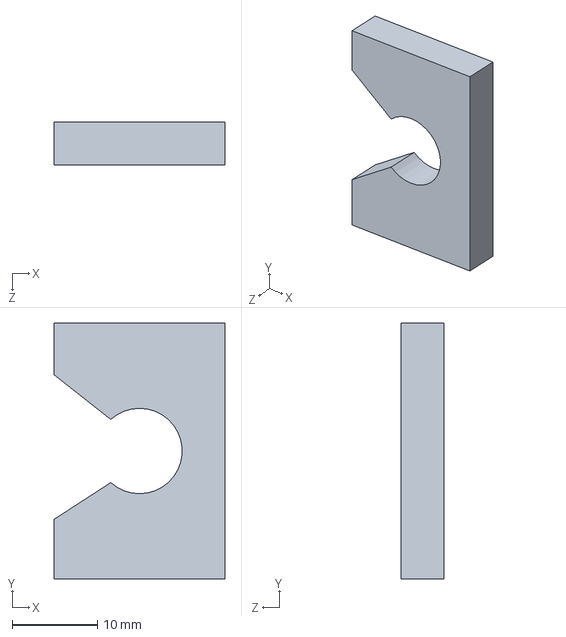
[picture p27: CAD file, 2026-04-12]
active-suspension/ActiveSuspension_kh/ActiveSuspension/Solidworks/Maintien2.SLDPRT
20.0 x 30.0 x 5.00 mm

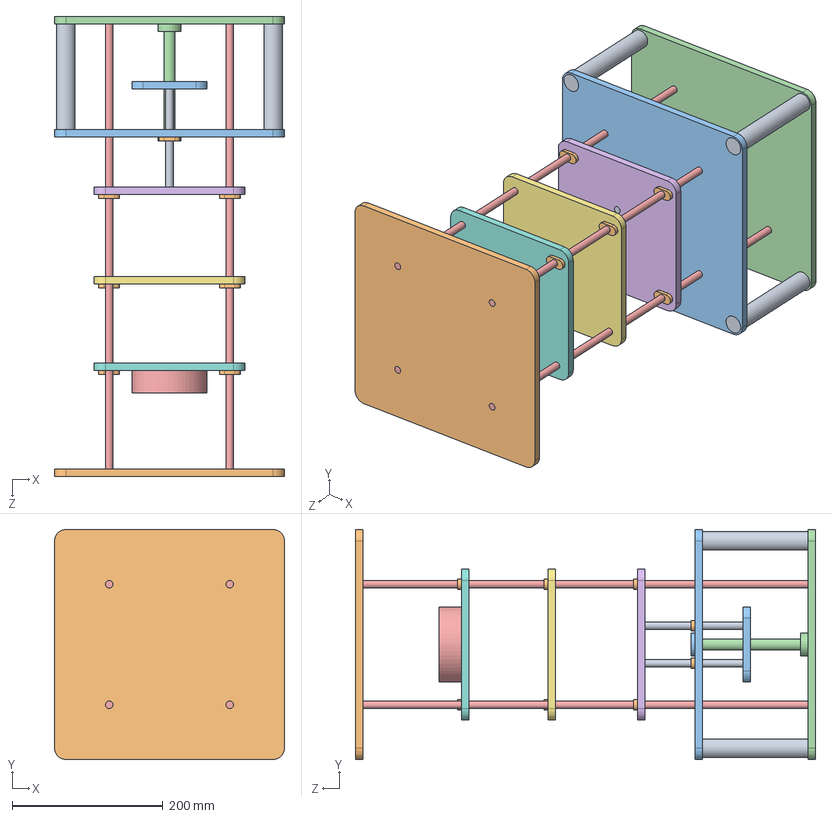
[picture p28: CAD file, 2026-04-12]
active-suspension/ActiveSuspension_kh/ActiveSuspension/Solidworks/ACTIVESUSPENSIONSYSTEM.SLDASM
305.0 x 305.0 x 610.0 mm
Colone x 4
BASEHAUT
BaseMillieu
BASE2
Longue_colone x 4
PLATEMillieubas
PLATEMillieu
PLATEMillieuHaut
colone_fine x 2
maintien x 10
PLATEsupportdoublet
ColoneMillieu
Poid

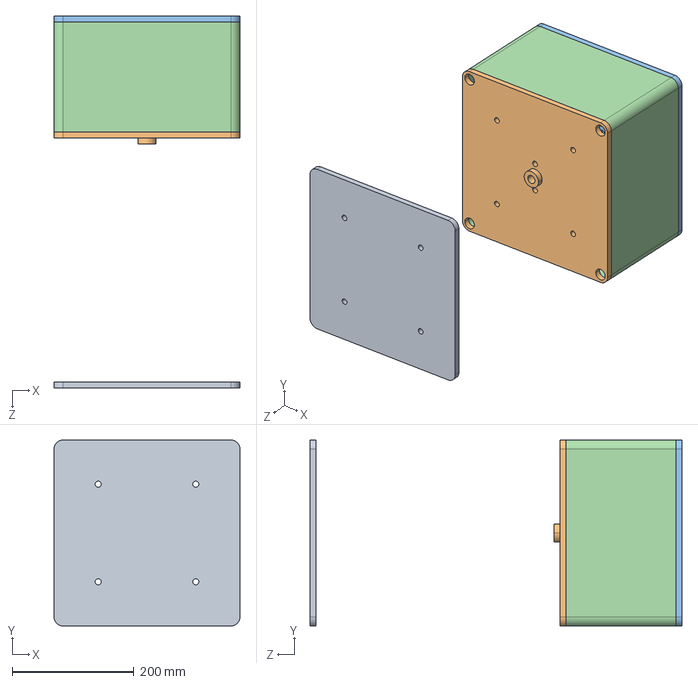
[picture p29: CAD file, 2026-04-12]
active-suspension/ActiveSuspension_kh/ActiveSuspension/Active_Suspension_System/ActiveSuspension/base_opt_Défaut_sldprt.STEP
305.0 x 305.0 x 610.0 mm

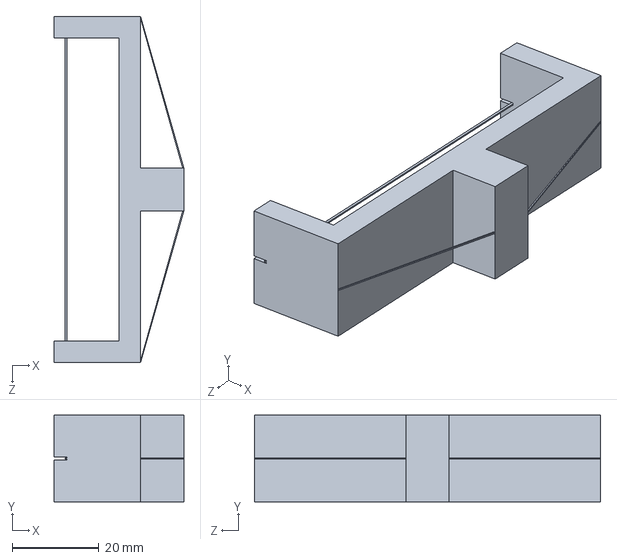
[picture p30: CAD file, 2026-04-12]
active-suspension/Simscape/ActiveSuspension-20211110T130043Z-001/ActiveSuspension/Active_Suspension_System/ActiveSuspension/moteur_bas_Défaut_sldprt.STEP
30.0 x 20.0 x 80.0 mm

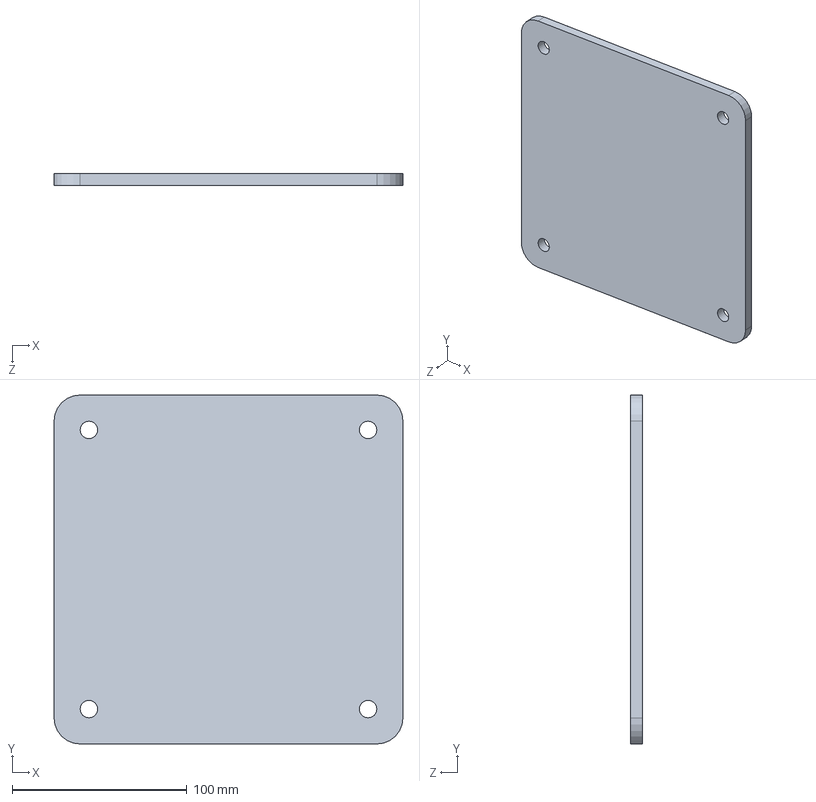
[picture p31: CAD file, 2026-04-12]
active-suspension/Simscape/ActiveSuspension-20211110T130043Z-001/ActiveSuspension/Solidworks/PLATEMillieuHaut.SLDPRT
200.0 x 200.0 x 7.00 mm

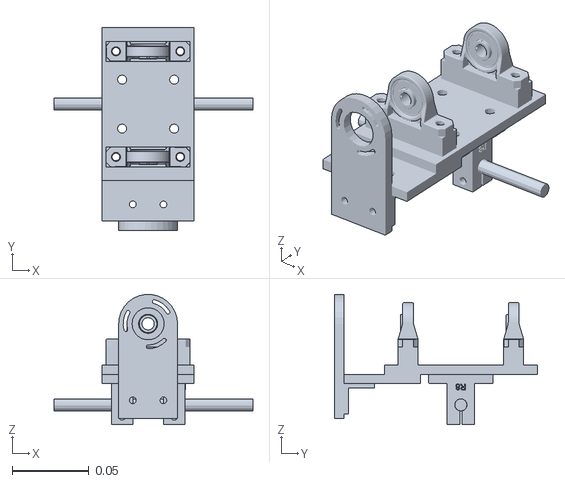
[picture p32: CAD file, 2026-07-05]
web-cloud/public/2dofhover/meshes/link1.STL
0.13 x 0.133 x 0.0849

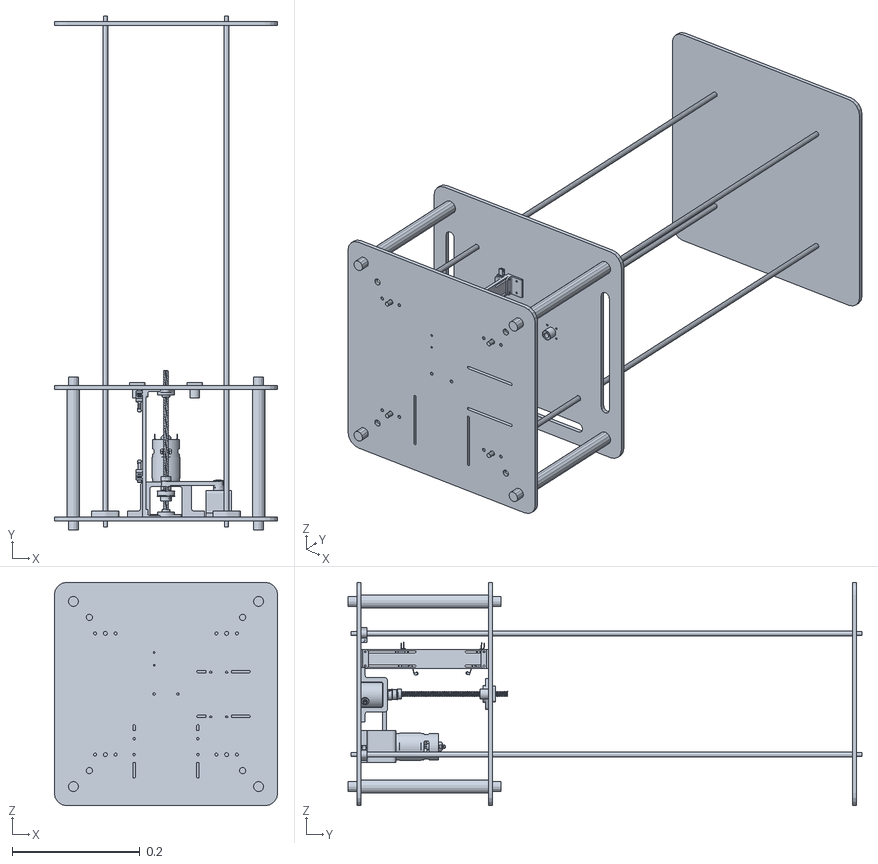
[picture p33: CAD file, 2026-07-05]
web-cloud/public/Active_Suspension_urdf/meshes/base_link.STL
0.35 x 0.805 x 0.35

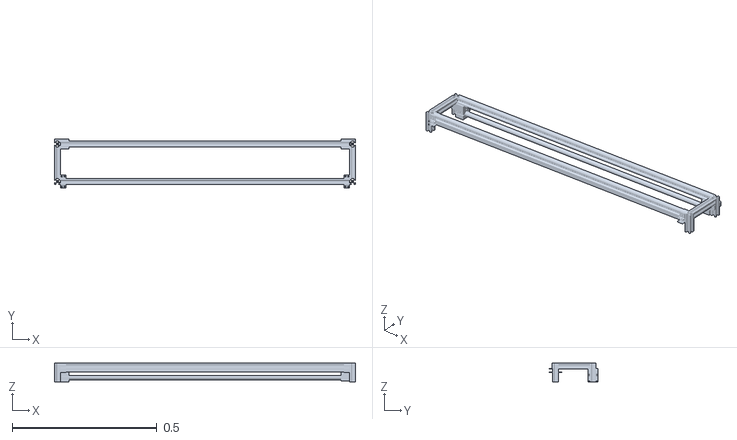
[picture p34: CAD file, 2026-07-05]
web-cloud/public/invurdf2/meshes/base_link.STL
1.04 x 0.169 x 0.065

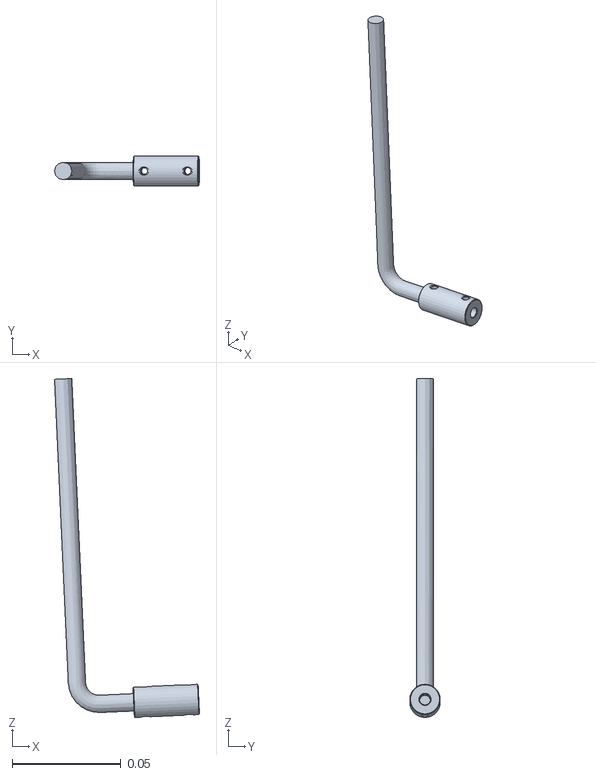
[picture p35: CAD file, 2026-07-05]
web-cloud/public/rotary_pendulum_urdf/meshes/pendulum_link_2.STL
0.0667 x 0.014 x 0.156

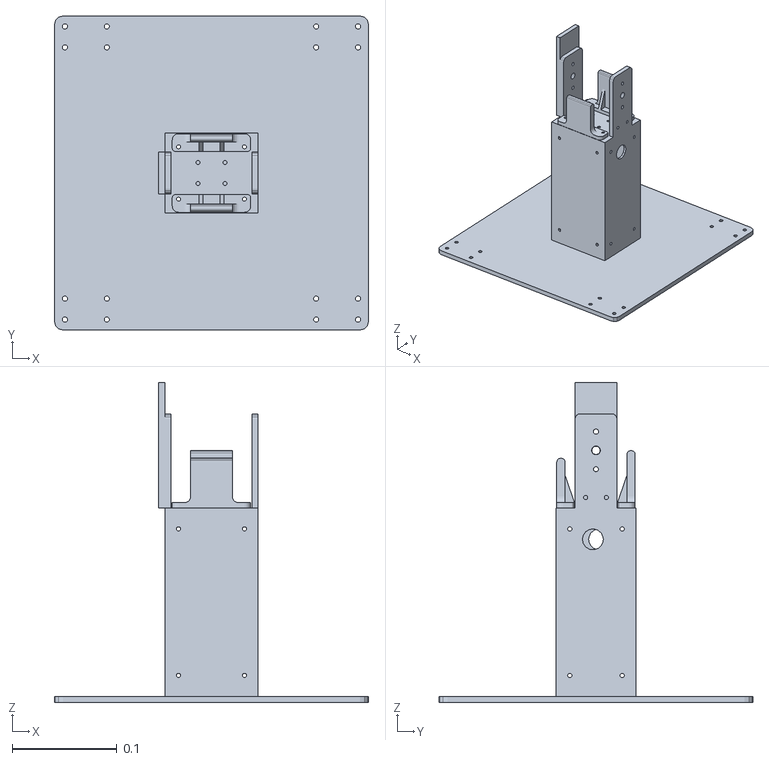
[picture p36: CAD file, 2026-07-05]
web-cloud/src/experiments/quadrotor/2dofhover/meshes/base_link.STL
0.3 x 0.3 x 0.306

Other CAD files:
active-suspension/Simscape/ActiveSuspension-20211110T130043Z-001/ActiveSuspension/Solidworks/ACTIVESUSPENSIONSYS.SLDASM
active-suspension/ActiveSuspension_kh/ActiveSuspension/Solidworks/ACTIVESUSPENSIONSYS.SLDASM
active-suspension/ActiveSuspension_kh/ActiveSuspension/Active_Suspension_System/ActiveSuspension/PLATEMillieuHaut_Défaut_sldprt.STEP
active-suspension/ActiveSuspension_kh/ActiveSuspension/Active_Suspension_System/ActiveSuspension/PLATEMillieu_Défaut_sldprt.STEP
active-suspension/ActiveSuspension_kh/ActiveSuspension/Active_Suspension_System/ActiveSuspension/PLATEMillieubas_Défaut_sldprt.STEP
active-suspension/ActiveSuspension_kh/ActiveSuspension/Active_Suspension_System/ActiveSuspension/Poid_Défaut_sldprt.STEP
active-suspension/ActiveSuspension_kh/ActiveSuspension/Active_Suspension_System/ActiveSuspension/barre_plate_bas_Défaut_sldprt.STEP
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

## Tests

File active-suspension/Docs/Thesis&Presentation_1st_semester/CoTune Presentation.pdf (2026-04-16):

# CoTune

### Supervised by: Dr Mohamed Omar El-Shalakani

# Our Team

Adham Ehab Saleh Mokhtar | 2100679
Abdelrahman Hany Abdelrahman Omar | 2100359
Ahmed Mohamed Ramadan | 2100323
Ahmed Yasser Hosny | 2101101
Khaled Amin Abdullah | 2100808
Omar Mohamed Fathy Ibrahim | 2100503

‹ 1 ›

Problem, Solution, Motivation

Overview, Mechanical Model, Dynamic Model, Sensors,
State Space, Control,
Simulink

01

02

Overview, Mathematical
Model, Parameter Estimation, Control, Simscape

03

‹ 2 ›

## Introduction

## Active Suspension Experiment Inverted Pendulum Experiment

# 01 Introduciton

‹ 3 ›

# The Problem with Traditional Labs

## Scheduling Constraints

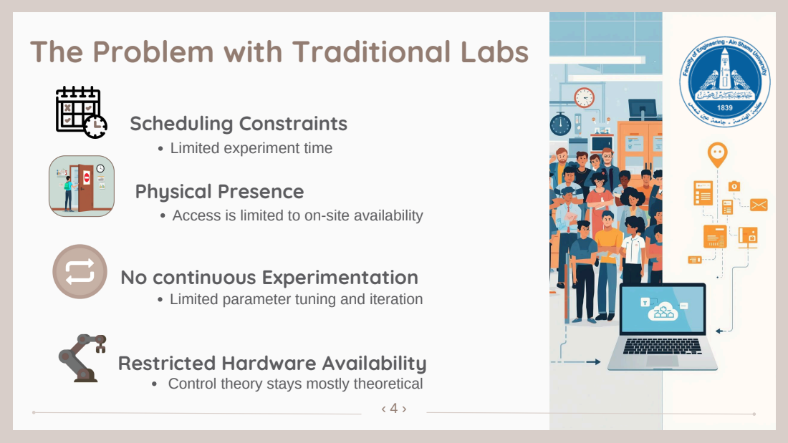
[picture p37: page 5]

Limited experiment time
Physical Presence
Access is limited to on-site availability

No continuous Experimentation
Limited parameter tuning and iteration

Restricted Hardware Availability

Control theory stays mostly theoretical

# Solution: CoTune Control Lab

## Remote Access

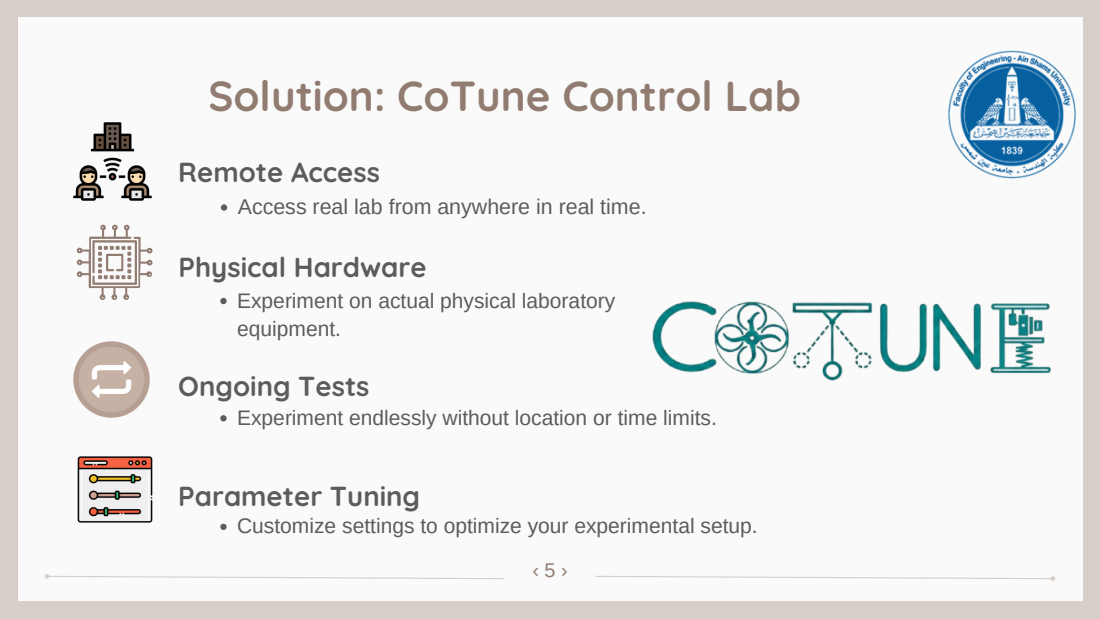
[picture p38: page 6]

Access real lab from anywhere in real time.
Physical Hardware
Experiment on actual physical laboratory
equipment.
Ongoing Tests
Experiment endlessly without location or time limits.

Parameter Tuning
Customize settings to optimize your experimental setup.

# Motivation for New Systems

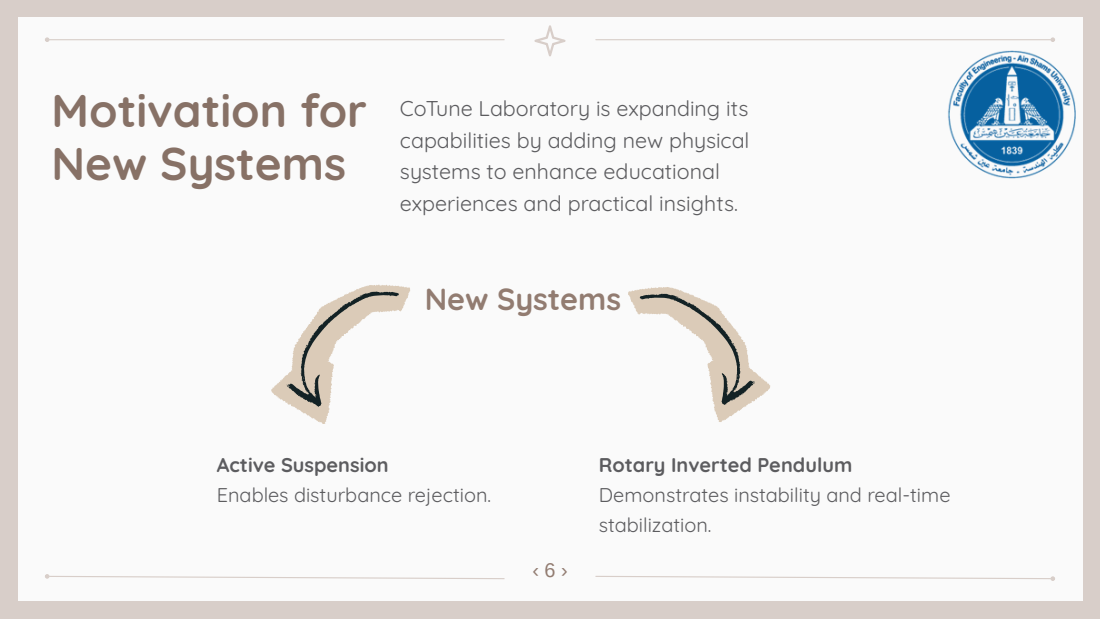
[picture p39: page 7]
New Systems

CoTune Laboratory is expanding its
capabilities by adding new physical
systems to enhance educational
experiences and practical insights.

Active Suspension
Enables disturbance rejection.

Rotary Inverted Pendulum
Demonstrates instability and real-time
stabilization.

# Active Suspension

02

‹ 7 ›

# Suspension System Overview

# Load Support

The suspension system supports vehicle weight while isolating the body from road disturbances for a smoother ride.

# Tire Contact

Maintaining consistent tire-road contact is crucial for vehicle stability, enhancing traction and overall handling performance.

# Spring Mechanics

Springs absorb energy from road impacts, while dampers dissipate energy to control oscillations for vehicle stability.

# Comfort vs. Handling

There is a fundamental trade-off between ride comfort and responsive handling, influencing suspension design and vehicle dynamics.

‹ 8 ›

# Types of Suspension Systems

### PASSIVE SUSPENSIONS:

Simple and cost-effective.

They consist of a spring (KS) and a damper (CS) which is fixed parameters defined during the design phase.

‹ 9 ›

# Types of Suspension Systems

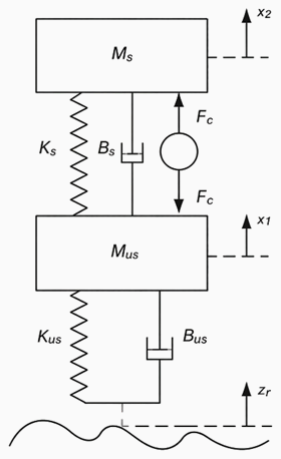
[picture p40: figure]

### ACTIVE SUSPENSIONS:

Controlled actuation between vehicle body and wheel based on sensor feedback

Real-time disturbance rejection instead of passive energy dissipation

‹ 10 ›

‹ 11 ›

# The Overall Mechanical Architecture

## Inspired by Quanser Benchmark

Top Plate — Sprung Mass (Vehicle Body)

Middle Plate — Unsprung Mass (Wheel Assembly)

Bottom Plate — Road Input (Base Excitation)

This arrangement allows the system to physically emulate the classical quarter-car suspension model, where:

Relative displacement between the top and middle plates corresponds to suspension travel Relative displacement between the middle and bottom corresponds to tire deflection

# Assembly

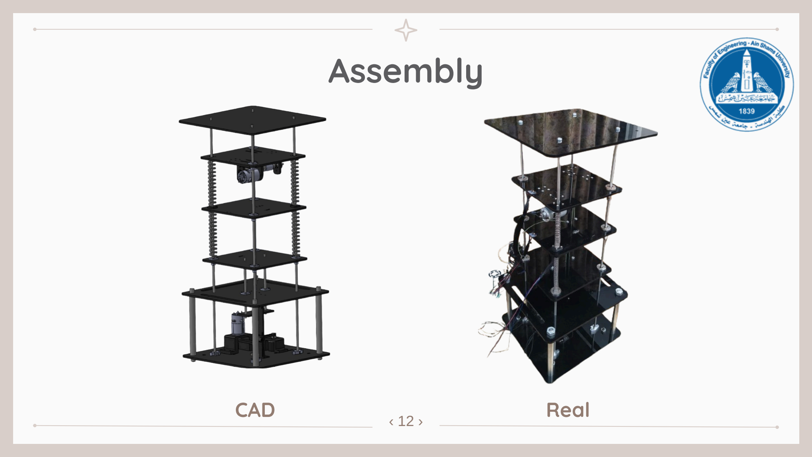
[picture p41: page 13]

CAD | Real
‹ 12 ›

# Capstan Mechanism

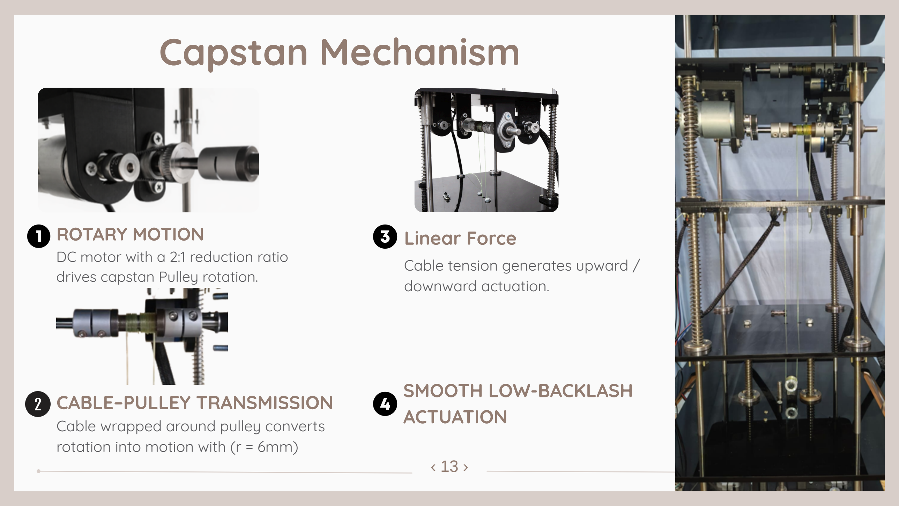
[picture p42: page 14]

### ROTARY MOTION

DC motor with a 2:1 reduction ratio drives capstan Pulley rotation.

### CABLE–PULLEY TRANSMISSION

Cable wrapped around pulley converts rotation into motion with (r = 6mm)
‹ 13 ›

Cable tension generates upward / downward actuation.

### Linear Force

### SMOOTH LOW-BACKLASH ACTUATION

ROTARY MOTION
DC motor with a 2:1 Gear ratio drives Screw Rotation.

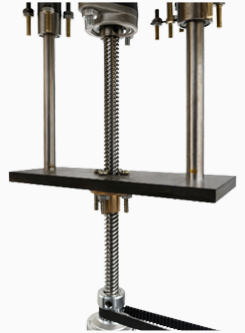
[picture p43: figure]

LEAD SCREW TRANSMISSION
Nut converts rotation into linear motion (Pitch = 8 mm / rev)

‹ 14 ›

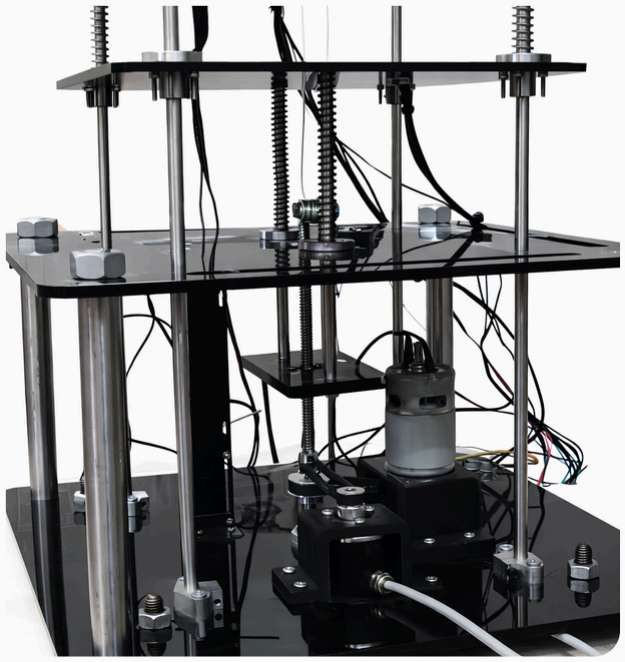
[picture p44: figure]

Controlled base plate motion.

PRECISE VERTICAL DISPLACEMENT

# Lead Screw Mechanism

## For Road Excitation Actuator

# Sensor Selection

For Acceleration Measurement | Dynamic Response Measurment Captures real-time vibration and ride comfort behavior.

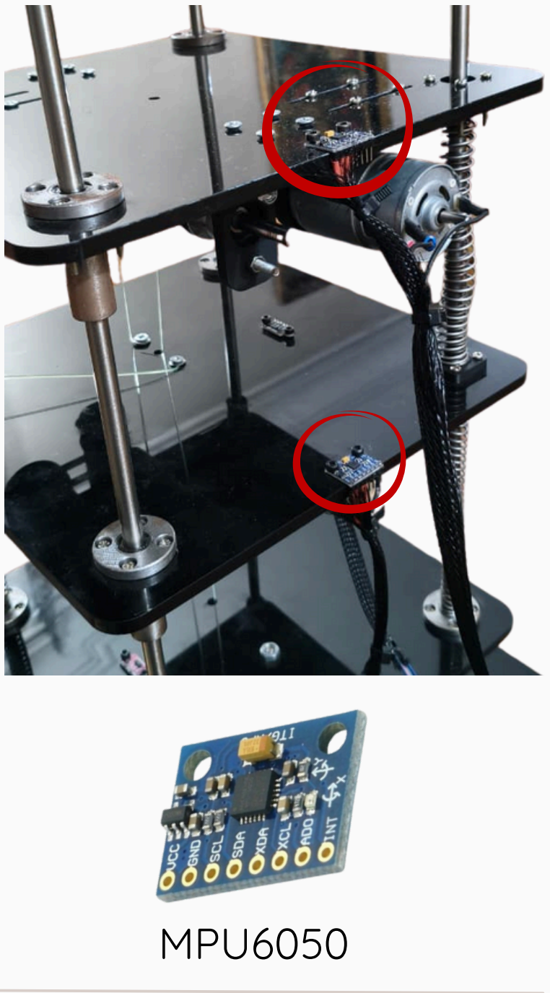
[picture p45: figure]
MPU6050

| Compact Integrated IMU 3-axis accelerometer + gyroscope in a single module (I²C).
| Dual-Plate acceleration sensing Vertical acceleration measured on sprung and unsprung masses.
| High-Resultion Configuration Accelerometerrange set to ±2 g for small vibration sensing.

Sensor 1 — Top Plate

Sensor 2 — Middle Plate

‹ 16 ›

# Sensor Selection

## For Displacement Measurement

### Non-Contact Measurement

Two ToFsensors avoid friction and mass loading.

### Relative Displacement

Vertical relative displacement measured across suspension stages.

### Real-Time Measurement

Sufficient accuracy and sampling rate for closed-loop control.

### Easy Integration

Simple I2C interface for seamless system integration.

VL53L0X

‹ 15 ›

# Sensor Interfacing

### THE CHALLENGE: I2C ADDRESS CONFLICTS

‹ 17 ›

All sensors (ToF and MPU6050) communicate via a shared I2C bus at 3.3V.

While MPU sensors have hardware pins to change addresses, the VL53L0X (ToF) sensors have a fixed default address.

Using two identical ToF sensors simultaneously on one bus causes a collision, making standard initialization impossible.

# Sensor Interfacing

### THE SOLUTION: XSHUT SEQUENCING & S-FUNCTION

‹ 18 ›

To resolve this, we implemented a sequential startup strategy using the XSHUT pin of each ToF sensor:

Sequential Bring-up: The ESP32 triggers the XSHUT pins to enable each ToF sensor one at a time.

Dynamic Reassignment: Each sensor is assigned a unique I2C address in software immediately upon "wake-up" to avoid bus collisions.

Custom S-Function: A tailored C++ S-Function manages this timing-critical initialization, ensuring a deterministic startup before the control loop begins.

# Quarter-Car Suspension Model

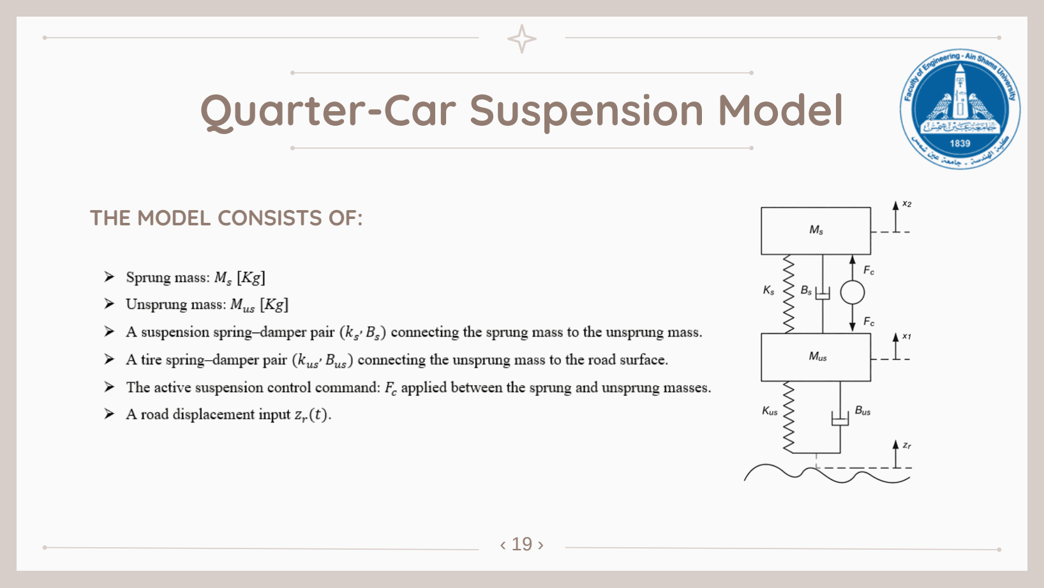
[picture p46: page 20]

### THE MODEL CONSISTS OF:

‹ 19 ›

‹ 21 ›

To optimize performance, we transform our 2-DOF differential equations into a state-space model:

State Vector (x): Captures the four energy storage elements of the system.

x1: Suspension Deflection (zs - zu) x2: Body Velocity (zs_dot)
x3: Tire Deflection (zu - zr)
x4: Tire Velocity (zu_dot)

Output Vector (y): Focused on measured suspension and tire deflection for real-time feedback.

# State Space Model

## Quarter-Car Dynamic Model

‹ 22 ›

# State Space Matrices

SYSTEM MATRIX (A) | INPUT MATRIX (B)
OUTPUT MATRIX (C) | FEEDTHROUGH MATRIX (D)

‹ 23 ›

Rather than arbitrarily placing poles, which can lead to unrealistic actuator demands, we use LQR to minimize a quadratic cost function J:

Physical Tuning (Q & R): We assign weights to each state (Q) and the control effort (R). This allows us to balance "Passenger Comfort" against "Actuator Limits."

# Control Algorithm

## Quarter-Car Dynamic Model

# Simscape Multibody

## Simulation


‹ 24 ›

# Full System Demonstration

## Active Suspension

‹ 25 ›


Road excitation sinsoudal input | Working capstain mechanism

# Rotary Inverted Pendulum

03

‹ 26 ›

# what is an Inverted Pendulum

A PENDULUM THAT HAS ITS CENTER OF MASS ABOVE ITS PIVOT POINT.

Inherently unstable.
Must be actively balanced in order to remain upright. Must have a feedback system to keep it balanced.

‹ 27 ›

# Types of Inverted Pendulum


IN GENERAL, TWO TYPES:

Linear Inverted pendulum
Rotary Inverted pendulum
Moving the pivot point horizontally | Applying a Torque at the pivot point
‹ 28 ›

‹ 29 ›

# The Overall Mechanical Architecture

## Inspired by Quanser Benchmark

ROTARY ARM—ACTUATED AXIS

PENDULUM LINK— FREE ROTATION

UNDERACTUATED SYSTEM

Horizontally rotating arm driven about a fixed vertical axis.

Pendulum rotates freely in the vertical plane.

Two coupled degrees of freedom with single actuation.

UNSTABLE UPRIGHT EQUILIBRIUM Upright position represents an unstable operating point.

# Assembly


CAD | Real

‹ 30 ›

# Mathematical Model

Linearization

Equation of Motion

State Space Model

# Motor Parameter Estimation

Motor Model

WHY ESTIMATION
Accurate actuator dynamics
for LQR design

ESTIMATED PARAMETERS
Armature resistance R
Armature inductance L
Torque constant Kt
Rotor inertia J
Viscous damping D

# System Parameter Estimation


ESTIMATION STRATEGY
Motor parameters fixed from Stage 1
Full arm–pendulum dynamic model used

ESTIMATED PARAMETERS
Rotary arm inertia Jr
Pendulum inertia Jp
Rotary arm viscous damping Br
Pendulum viscous damping Bp

System Linear Model

### SWING-UP CONTROL

# Control Strategy

## Essential strategies for rotary systems

### STABILIZATION CONTROL

Once the pendulum reaches the vicinity of the upright position, a linear controller is activated to stabilize and maintain the pendulum around this unstable equilibrium.

A nonlinear control law is used to transfer the pendulum from its stable downward equilibrium to a region close to the upright configuration.

‹ 34 ›


# Swing-Up Control

## Rotary Inverted Pendulum

### METHOD

Energy-based swing-up control to elevate the pendulum.

A switching condition was applied: |α| < 15° → Switch to stabilization controller

### ACTUATION

Motor torque applied through rotary arm for movement.

### MODE SWITCHING

Automatic transition to LQR near upright position.

‹ 35 ›

# Stabilization Using LQR

## Upright Stabilization Using Optimal State Feedback

‹ 36 ›

# Simscape Multibody Physical Model

## Imported Mechanical CAD into Simscape Multibody


‹ 37 ›

# Simscape Multibody Physical Model

## Then add the LQR and swing up controller

‹ 38 ›

# Simscape Multibody Physical Model

## Simulation


‹ 39 ›

# Simscape Multibody Physical Model

## Simulation Results


‹ 40 ›

Theta | Theta dot

# Simscape Multibody Physical Model

## Simulation Results


‹ 41 ›

Alpha | Alpha dot

# Full System Demonstration

## Rotary Inverted Pendulum

‹ 42 ›

# Conclusion

‹ 43 ›

Active Suspension System

Framework: Developed a complete mechanical and electrical architecture using a unified SolidWorks–Simscape workflow.

Performance: Simulation of the LQR controller demonstrated significant improvements in ride comfort, road handling, and suspension travel over passive systems.

This project successfully developed and validated two modular, high-fidelity experimental platforms designed to bridge the gap between theoretical control and real-world hardware.

# Conclusion

‹ 44 ›

Rotary Inverted Pendulum

Achieved successful real-time stabilization on the physical plant, confirming high consistency between the dynamic model and experimental behavior.

Robust hands-on platform for studying unstable systems and real-time control strategies.

Project Impact

Integrated mechanical design, electrical interfacing, and advanced control within a single educational ecosystem.

Both platforms are fully prepared for integration into the CoTune remote-access laboratory, supporting flexible and continuous engineering education.

# Practical Challenges

‹ 45 ›

Issue: String slippage and loss of tension during rapid downward movements.

Root Cause: Insufficient mechanical engagement between the cable & the motor pulley.

Solution: Redesigned the pulley with a internal guiding hole. Routing the string through the pulley core ensured positive engagement and eliminated slippage.

## 2. Capstan Mechanism Tension Loss

# Practical Challenges

Issue: Extremely low encoder resolution (7 PPR) on the rotary arm motor.

Impact: Coarse angular steps (~3°) made it impossible to detect the fine deviations required for upright stabilization.

Planned Mitigation: Replacing the existing motor assembly with a high-resolution optical encoder to provide the precision needed for LQR balancing.

## 3. Quantization in Rotary Pendulum

‹ 46 ›

# Future

0 1

SENSOR FUSION; DIGITAL TWIN; RL TUTOR; Road map

Kalman Filter Integration to
Fuse ToF and IMU data for
accurate state estimation.
(week 1-2)

HARDWARE DEPLOYMENT
Real-Time Control Implementation

Deploy controllers on physical
suspension hardware. (week 2)

CLOUD MPC (CNMPC)

Remote Optimization Control
Implement MPC via CoTune cloud
interface. (week 6)

Live Simulation Synchronization
Real-time data linked with
simulation models. (week 10)

Reinforcement Learning Module
Compare RL performance
against LQR and MPC. (week 12)

# Thank You!


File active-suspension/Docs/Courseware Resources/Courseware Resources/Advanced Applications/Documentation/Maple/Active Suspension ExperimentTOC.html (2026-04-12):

Active Suspension Experiment.mw

- Description
  - The Quanser_Tools Package
- Worksheet Initialization
- Notations
  - Generalized Coordinates: NULL's
    - Figure 1: System Schematic
  - State-Space Variables
- Total Potential and Kinetic Energies of the System
  - Total Potential Energy: NULL
  - Total Kinetic Energy: NULL
- Generalized Forces: NULL's
- Euler-Lagrange's Equations
  - Additional Insight: Eliminating Gravity Terms
  - Additional Insight: Inertia (or mass) Matrix: Fi
- Solving the Euler-Lagrange's Equations
  - Reverse State Substitution for Pretty Display of the Solved EOM's
  - Solution to the (Linear) EOM's
- Determine the System State-Space Matrices: A, B, C, and D
- Determine the System New State-Space Matrices: A, B, C, and D
- Determine the Transtere Functions
- Write A, B, C, and D to a Matlab file
- Procedure Printing

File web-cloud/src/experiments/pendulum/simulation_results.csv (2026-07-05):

Time | XPosition | XVelocity | Angle | AngularVelocity
0 | 0 | 1.6128962237606404e-10 | 3.12413936106985 | 0.0005582854251648257
0.001 | 1.6128962237606405e-13 | -0.008418990508207252 | 3.12413936106985 | 0.001116567019358836
0.002 | -0.00000841899034691763 | -0.01755494157601359 | 3.124139919355275 | 0.029123802548015124
0.003 | -0.000025973931922931216 | -0.026736762307613904 | 3.1241410359222943 | 0.05946840509674553
0.004 | -0.00005271069423054512 | -0.03590591720331147 | 3.1241701597248426 | 0.08996234458048974
0.005 | -0.00008861661143385658 | -0.045057220116462945 | 3.1242296281299393 | 0.12041389200920036
0.006 | -0.00013367383155031952 | -0.054190132796174684 | 3.12431959047452 | 0.15080518402118442
0.007 | -0.0001878639643464942 | -0.06330452280231039 | 3.124440004366529 | 0.18113350622212582
0.008 | -0.0002511684871488046 | -0.07240029394774403 | 3.12459080955055 | 0.21139746831339018
0.009000000000000001 | -0.00032356878109654865 | -0.08147735410309132 | 3.124771943056772 | 0.24159579967211636
0.01 | -0.00040504613519963995 | -0.09053561239618824 | 3.1249833405250853 | 0.27172724438723994
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

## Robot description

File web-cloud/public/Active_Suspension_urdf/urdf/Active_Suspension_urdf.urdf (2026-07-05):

<?xml version="1.0" encoding="utf-8"?>
<!-- This URDF was automatically created by SolidWorks to URDF Exporter! Originally created by Stephen Brawner (brawner@gmail.com) 
     Commit Version: 1.6.0-4-g7f85cfe  Build Version: 1.6.7995.38578
     For more information, please see http://wiki.ros.org/sw_urdf_exporter -->
<robot name="Active_Suspension_urdf">
  <link name="base_link">
    <inertial>
      <origin xyz="0.0017852 0.28483 -0.0022167" rpy="0 0 0" />
      <mass value="2.8852" />
      <inertia ixx="0.031256" ixy="3.9095E-10" ixz="-3.2805E-07" iyy="0.042918" iyz="-1.1608E-08" izz="0.031032" />
    </inertial>
    <visual>
      <origin xyz="0 0 0" rpy="0 0 0" />
      <geometry>
        <mesh filename="package://Active_Suspension_urdf/meshes/base_link.STL" />
      </geometry>
      <material name="">
        <color rgba="0.79216 0.81961 0.93333 1" />
      </material>
    </visual>
    <collision>
      <origin xyz="0 0 0" rpy="0 0 0" />
      <geometry>
        <mesh filename="package://Active_Suspension_urdf/meshes/base_link.STL" />
      </geometry>
    </collision>
  </link>
  <link name="link_1">
    <inertial>
      <origin xyz="-5.0869E-09 -0.021265 5.7292E-05" rpy="0 0 0" />
      <mass value="0.44228" />
      <inertia ixx="0.0019585" ixy="-4.1039E-11" ixz="6.8978E-12" iyy="0.0038319" iyz="-3.864E-11" izz="0.0019942" />
    </inertial>
    <visual>
      <origin xyz="0 0 0" rpy="0 0 0" />
      <geometry>
        <mesh filename="package://Active_Suspension_urdf/meshes/link_1.STL" />
      </geometry>
      <material name="">
        <color rgba="0.79216 0.81961 0.93333 1" />
      </material>
    </visual>
    <collision>
      <origin xyz="0 0 0" rpy="0 0 0" />
      <geometry>
        <mesh filename="package://Active_Suspension_urdf/meshes/link_1.STL" />
      </geometry>
    </collision>
  </link>
  <joint name="joint_1" type="prismatic">
    <origin xyz="0 0.30472 0" rpy="0 0 0" />
    <parent link="base_link" />
    <child link="link_1" />
    <axis xyz="0 1 0" />
    <limit lower="-0.018" upper="-0.018" effort="100" velocity="0.3" />
  </joint>
  <link name="link_2">
    <inertial>
      <origin xyz="1.8428E-06 -0.0029708 -6.5349E-05" rpy="0 0 0" />
      <mass value="0.38813" />
      <inertia ixx="0.0018924" ixy="-3.6425E-12" ixz="-4.9358E-11" iyy="0.0037817" iyz="2.0856E-11" izz="0.0018926" />
    </inertial>
    <visual>
      <origin xyz="0 0 0" rpy="0 0 0" />
      <geometry>
        <mesh filename="package://Active_Suspension_urdf/meshes/link_2.STL" />
      </geometry>
      <material name="">
        <color rgba="0.79216 0.81961 0.93333 1" />
      </material>
    </visual>
    <collision>
      <origin xyz="0 0 0" rpy="0 0 0" />
      <geometry>
        <mesh filename="package://Active_Suspension_urdf/meshes/link_2.STL" />
      </geometry>
    </collision>
  </link>
  <joint name="joint_2" type="prismatic">
    <origin xyz="0 0.12957 0" rpy="0 0 0" />
    <parent link="link_1" />
    <child link="link_2" />
    <axis xyz="0 1 0" />
    <limit lower="-0.0175" upper="0.0175" effort="0" velocity="0.3" />
  </joint>
  <link name="link_3">
    <inertial>
      <origin xyz="0.0046856 -0.015674 2.5684E-05" rpy="0 0 0" />
      <mass value="0.60901" />
      <inertia ixx="0.0019559" ixy="1.7858E-05" ixz="-1.4489E-05" iyy="0.0038406" iyz="-1.9353E-08" izz="0.0019914" />
    </inertial>
    <visual>
      <origin xyz="0 0 0" rpy="0 0 0" />
      <geometry>
        <mesh filename="package://Active_Suspension_urdf/meshes/link_3.STL" />
      </geometry>
      <material name="">
        <color rgba="0.79216 0.81961 0.93333 1" />
      </material>
    </visual>
    <collision>
      <origin xyz="0 0 0" rpy="0 0 0" />
      <geometry>
        <mesh filename="package://Active_Suspension_urdf/meshes/link_3.STL" />
      </geometry>
    </collision>
  </link>
  <joint name="joint_3" type="prismatic">
    <origin xyz="0 0.20176 0" rpy="0 0 0" />
    <parent link="link_2" />
    <child link="link_3" />
    <axis xyz="0 1 0" />
    <limit lower="-0.019" upper="0.019" effort="38.3" velocity="0.3" />
  </joint>
</robot>

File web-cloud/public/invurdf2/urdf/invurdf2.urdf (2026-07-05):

<?xml version="1.0" encoding="utf-8"?>
<!-- This URDF was automatically created by SolidWorks to URDF Exporter! Originally created by Stephen Brawner (brawner@gmail.com) 
     Commit Version: 1.6.0-4-g7f85cfe  Build Version: 1.6.7995.38578
     For more information, please see http://wiki.ros.org/sw_urdf_exporter -->
<robot name="invurdf2">
  <link name="base_link">
    <inertial>
      <origin xyz="0.52134 0.080315 0.025851" rpy="0 0 0" />
      <mass value="3.6147" />
      <inertia ixx="0.00044888" ixy="-5.5123E-08" ixz="1.9241E-15" iyy="0.24504" iyz="9.1996E-19" izz="0.24517" />
    </inertial>
    <visual>
      <origin xyz="0 0 0" rpy="0 0 0" />
      <geometry>
        <mesh filename="../meshes/base_link.STL" scale="2.0 1.0 1.0" />
      </geometry>
      <material name="">
        <color rgba="0 0 0 1" />
      </material>
    </visual>
    <collision>
      <origin xyz="0 0 0" rpy="0 0 0" />
      <geometry>
        <mesh filename="../meshes/base_link.STL" />
      </geometry>
    </collision>
  </link>
  <link name="cart">
    <inertial>
      <origin xyz="-0.063158 -0.056692 0.040187" rpy="0 0 0" />
      <mass value="0.59648" />
      <inertia ixx="0.00028339" ixy="3.5327E-07" ixz="-1.8517E-07" iyy="0.00045456" iyz="-5.8837E-07" izz="0.00063141" />
    </inertial>
    <visual>
      <origin xyz="0 -0.52 0" rpy="0 0 0" />
      <geometry>
        <mesh filename="../meshes/cart.STL" />
      </geometry>
      <material name="">
        <color rgba="3 3 3 1" />
      </material>
    </visual>
    <collision>
      <origin xyz="0 0 0" rpy="0 0 0" />
      <geometry>
        <mesh filename="../meshes/cart.STL" />
      </geometry>
    </collision>
  </link>
  <joint name="joint1" type="prismatic">
    <origin xyz="-0.468 0.0206 -0.119" rpy="0 0 -1.5708" />
    <parent link="base_link" />
    <child link="cart" />
    <axis xyz="0 -1 0" />
    <limit lower="-0.856" upper="0.856" effort="15" velocity="3" />
  </joint>
  <link name="pendulum">
    <inertial>
      <origin xyz="-0.057311 -0.047096 -0.15465" rpy="0 0 0" />
      <mass value="0.30048" />
      <inertia ixx="0.0036729" ixy="-5.414E-05" ixz="-0.001318" iyy="0.0040827" iyz="-0.0001449" izz="0.00056101" />
    </inertial>
    <visual>
      <origin xyz="0 0 0" rpy="0 0 0" />
      <geometry>
        <mesh filename="../meshes/pendulum.STL" />
      </geometry>
      <material name="">
        <color rgba="1 1 1 1" />
      </material>
    </visual>
    <collision>
      <origin xyz="0 0 0" rpy="0 0 0" />
      <geometry>
        <mesh filename="../meshes/pendulum.STL" />
      </geometry>
    </collision>
  </link>
  <joint name="joint2" type="revolute">
    <origin xyz="0 -0.572199 -0.028" rpy="-3.1005 0.35113 -1.5708" />
    <parent link="cart" />
    <child link="pendulum" />
    <axis xyz="0 -0.99915720211753 0.0410473562689422" />
    <limit lower="-3.142" upper="3.142" effort="40" velocity="3" />
  </joint>
</robot>

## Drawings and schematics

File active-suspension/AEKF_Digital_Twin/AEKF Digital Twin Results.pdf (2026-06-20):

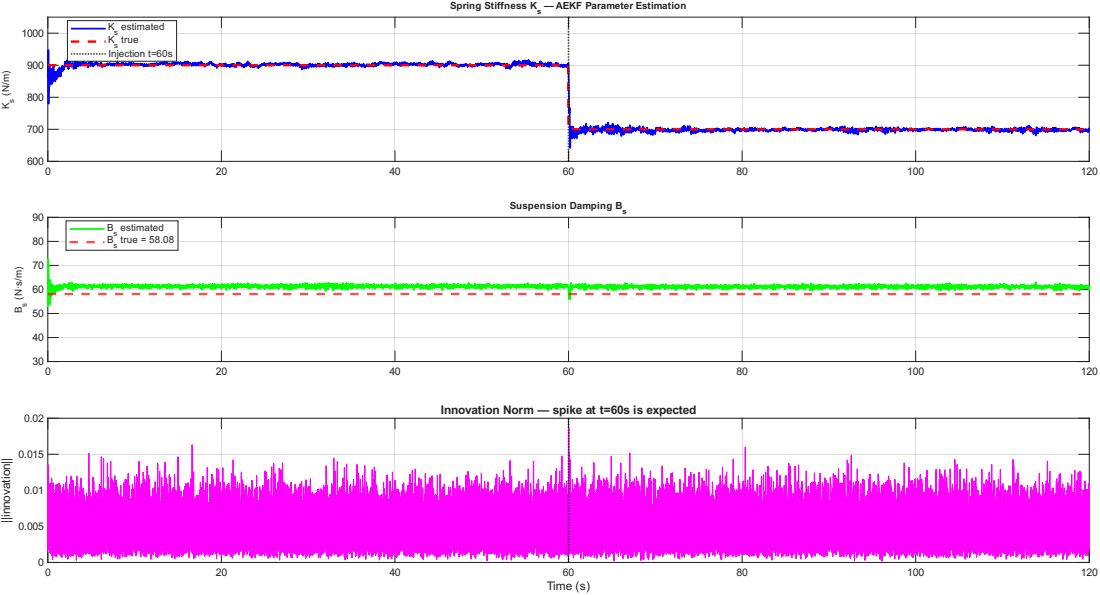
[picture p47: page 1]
rin; tif; tim; tio; sio; pin; Tim; ||innovation||; pik

K e s tim a t e d s
K t r u e Injectio s n t = 6 0 s

B e s tim a t e d s B t r u e = 5 8.0 8

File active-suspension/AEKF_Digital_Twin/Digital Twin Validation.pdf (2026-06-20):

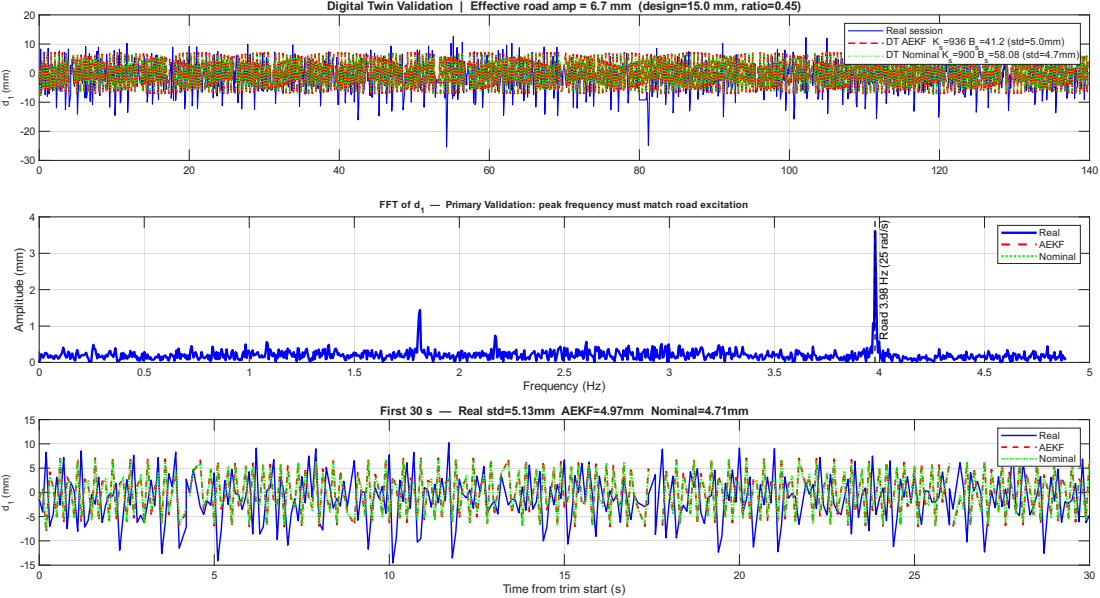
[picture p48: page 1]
Frequency (Hz); plitud; FFT of d; 5 rad/s)

Digital Twin Validation | Effective road amp = 6.7 mm (design=15.0 mm, ratio=0.45)

Real session DT AEKF Ks | =936 Bs =41.2 (std=5.0mm)

DT Nominal Ks | =900 Bs =58.08 (std=4.7mm)

1 — Primary Validation: peak frequency must match road excitation

Real AEKF

Nominal

First 30 s — Real std=5.13mm AEKF=4.97mm Nominal=4.71mm

Real
AEKF Nominal

Time from trim start (s)

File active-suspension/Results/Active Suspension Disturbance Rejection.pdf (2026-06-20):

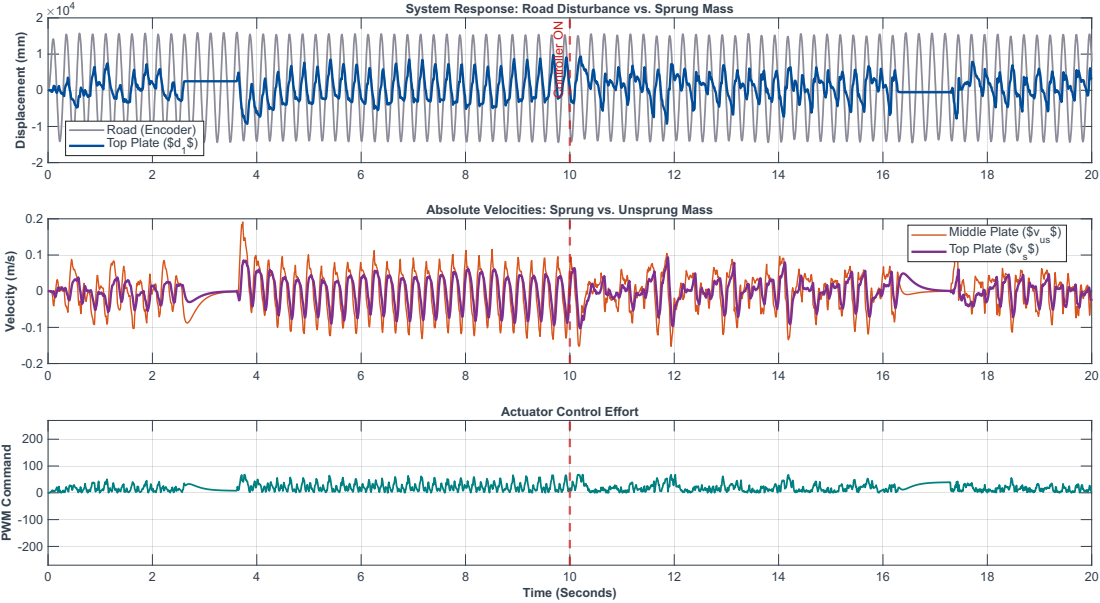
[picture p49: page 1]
Displacement (mm); Dis; Controller ON; Pla; Velocity (m/s); olu; Velo; citie; Mid; dle; Tim; PWM Command

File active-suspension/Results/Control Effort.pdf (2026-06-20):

A

c

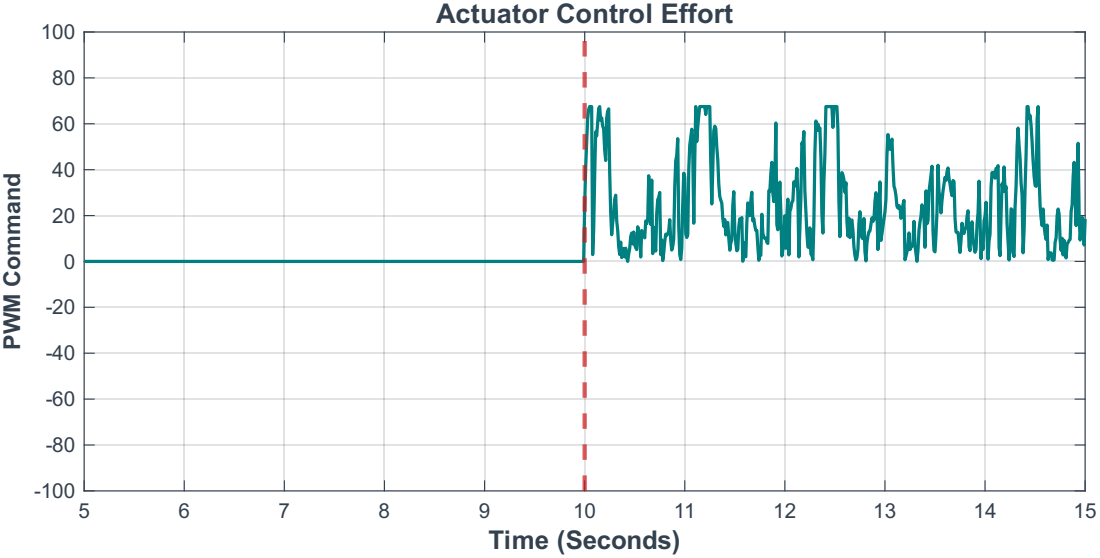
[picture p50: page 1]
Tim; PWM Command

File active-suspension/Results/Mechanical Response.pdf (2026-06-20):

## System Displacements: Road vs. Sprung Mass

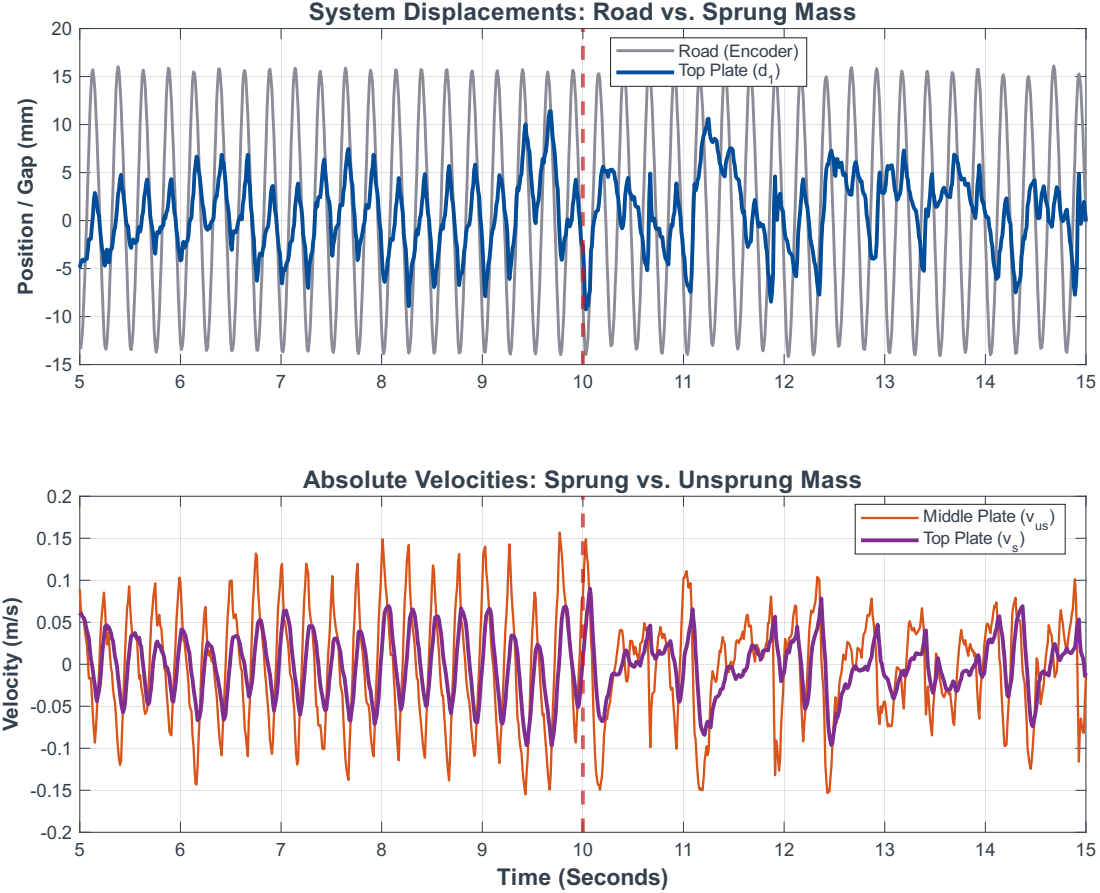
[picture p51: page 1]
sitio; Road (Encoder); Time (Seconds); Velo; city (m/s)

Top Plate (d | )

Absolute Velocities: Sprung vs. Unsprung Mass

Middle Plate (v Top Plate (v | ) us )

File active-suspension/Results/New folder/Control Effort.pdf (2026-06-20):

A

c

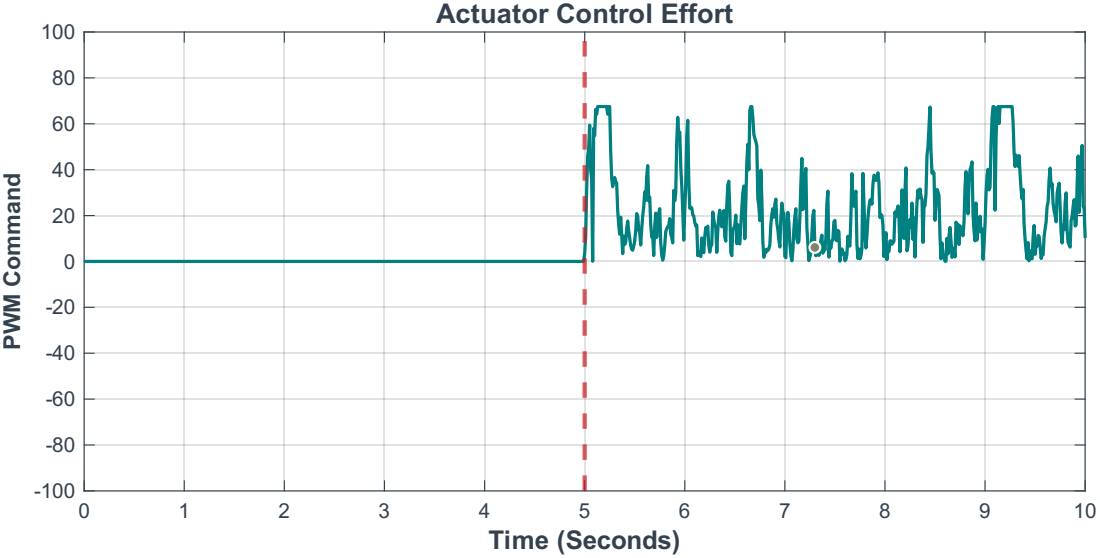
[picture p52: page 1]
Tim; PWM Command

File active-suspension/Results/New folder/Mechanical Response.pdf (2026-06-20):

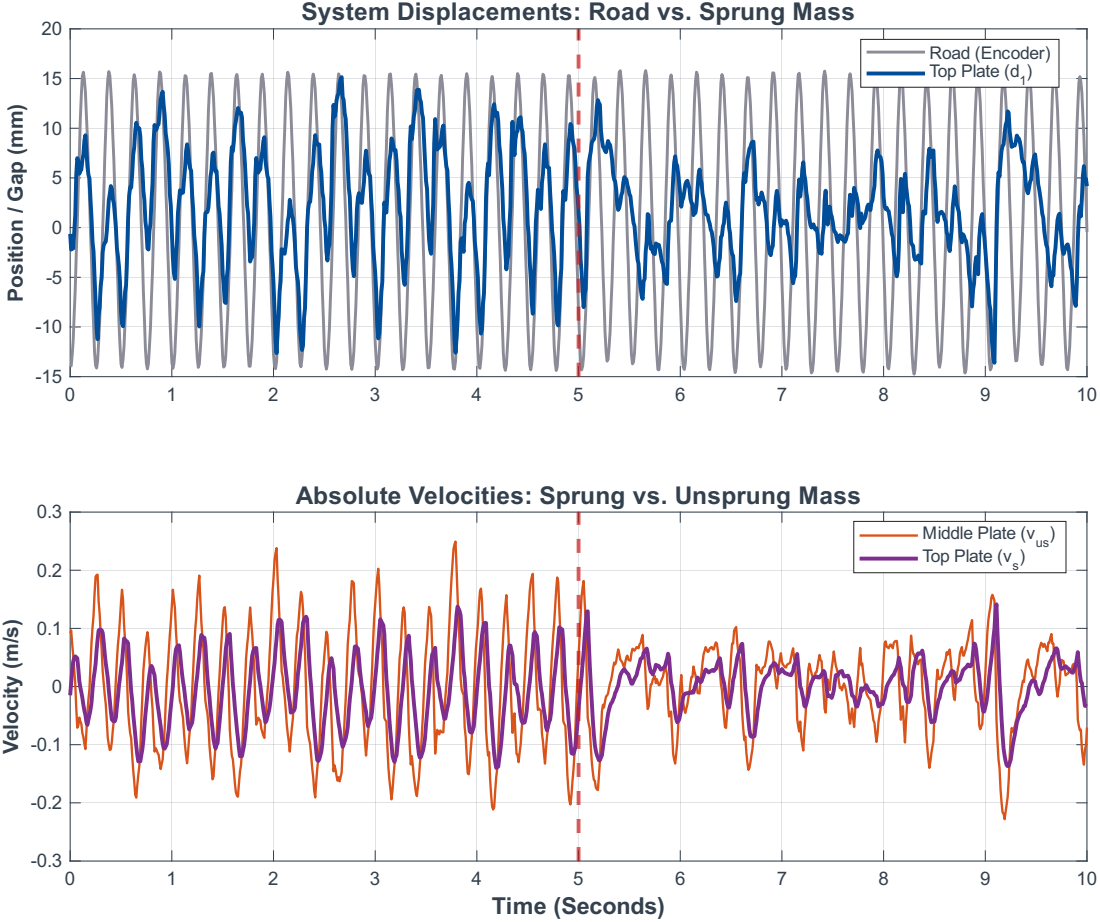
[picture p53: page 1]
sitio; Time (Seconds); Velo; city (m/s); Middle Plate (v; Top Plate (v

System Displacements: Road vs. Sprung Mass

Road (Encoder) Top Plate (d | )

Absolute Velocities: Sprung vs. Unsprung Mass

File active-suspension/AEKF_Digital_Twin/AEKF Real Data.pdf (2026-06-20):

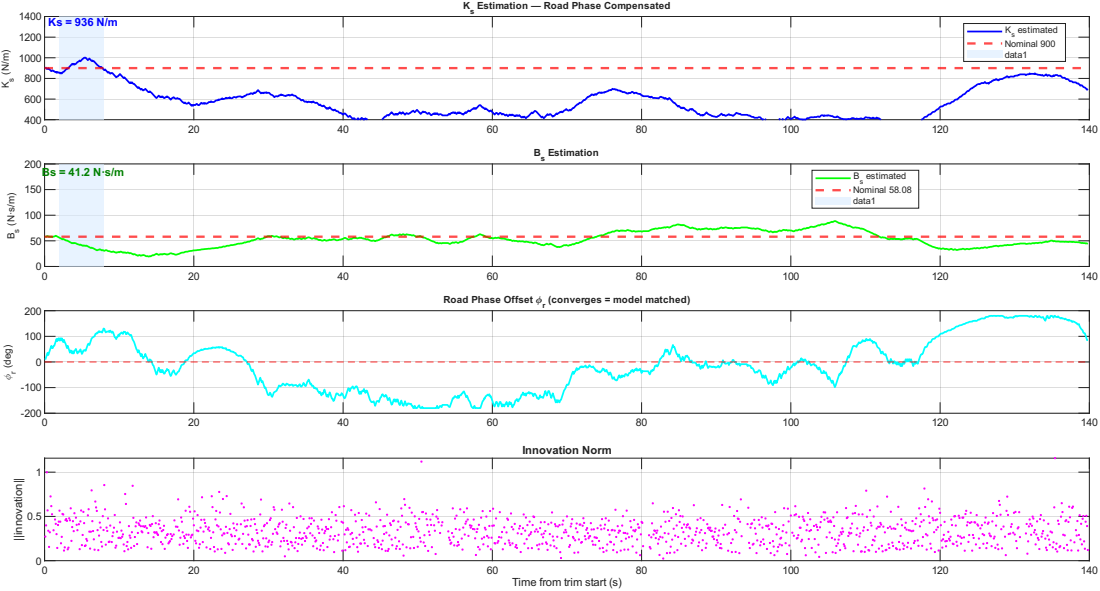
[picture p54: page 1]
tim; tio; ?r (deg); Tim; rim; ||innovation||

K s = 9 3 6 N / m | K e s tim a t e d s

N o min al 9 0 0 d a t a 1

s = 4 1.2 N·s / m | B e s tim a t e d s N o min al 5 8.0 8

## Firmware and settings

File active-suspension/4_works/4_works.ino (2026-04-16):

#include <Wire.h>
#include "Adafruit_VL53L0X.h"

// --- ToF Sensor Addresses & Pins ---
#define LOX1_ADDRESS 0x30
#define LOX2_ADDRESS 0x31
#define SHT_LOX1 25
#define SHT_LOX2 26

Adafruit_VL53L0X lox1 = Adafruit_VL53L0X();
Adafruit_VL53L0X lox2 = Adafruit_VL53L0X();

// --- MPU6050 Addresses ---
const int MPU1_ADDR = 0x68; // Requires AD0 connected to GND
const int MPU2_ADDR = 0x69; // Requires AD0 connected to 3.3V

// --- Median Filter Variables ---
const int WINDOW_SIZE = 5;
int buffer1[WINDOW_SIZE] = {0};
int buffer2[WINDOW_SIZE] = {0};
int index1 = 0;
int index2 = 0;

// --- Median Filter Function ---
int getMedian(int newValue, int *buffer, int &index) {
  buffer[index] = newValue;
  index = (index + 1) % WINDOW_SIZE;

  int temp[WINDOW_SIZE];
  for (int i = 0; i < WINDOW_SIZE; i++) {
    temp[i] = buffer[i];
  }

  // Bubble Sort
  for (int i = 0; i < WINDOW_SIZE - 1; i++) {
    for (int j = 0; j < WINDOW_SIZE - i - 1; j++) {
      if (temp[j] > temp[j + 1]) {
        int swap = temp[j];
        temp[j] = temp[j + 1];
        temp[j + 1] = swap;
      }
    }
  }
  return temp[WINDOW_SIZE / 2];
}

// --- MPU Wakeup & Config Function ---
void wakeUpMPU(int address) {
  // 1. Wake it up
  Wire.beginTransmission(address);
  Wire.write(0x6B);  // PWR_MGMT_1 register
  Wire.write(0);     // Set to 0 to wake up
  Wire.endTransmission(true);

  // 2. Turn on the Digital Low Pass Filter (DLPF)
  Wire.beginTransmission(address);
  Wire.write(0x1A);  // CONFIG register
  Wire.write(0x03);  // Set DLPF to 44Hz (Smooths out the jagged spikes)
  byte error = Wire.endTransmission(true);
  
  if (error != 0) {
    while(1); // Freeze if an MPU fails to prevent bad data
  }
}

// --- MPU Read Z-Axis Function ---
float readMPU_Z(int address) {
  Wire.beginTransmission(address);
  Wire.write(0x3B);  
  Wire.endTransmission(false); 
  Wire.requestFrom(address, 6, true);  
  
  // We have to read X and Y to clear the buffer
  int16_t rawX = Wire.read() << 8 | Wire.read();      
  int16_t rawY = Wire.read() << 8 | Wire.read();  
  int16_t rawZ = Wire.read() << 8 | Wire.read();  
  
  // Convert to m/s^2 and return
  return (rawZ / 16384.0) * 9.81;
}

void setup() {
  Serial.begin(115200);
  delay(2000); 

  Wire.begin();

  // --- 1. Wake up the MPUs ---
  wakeUpMPU(MPU1_ADDR);
  wakeUpMPU(MPU2_ADDR);

  // --- 2. Initialize ToF Sensors ---
  pinMode(SHT_LOX1, OUTPUT);
  pinMode(SHT_LOX2, OUTPUT);

  // Reset both ToFs
  digitalWrite(SHT_LOX1, LOW);
  digitalWrite(SHT_LOX2, LOW);
  delay(10);
  
  digitalWrite(SHT_LOX1, HIGH);
  digitalWrite(SHT_LOX2, HIGH);
  delay(10);

  // Isolate ToF 1
  digitalWrite(SHT_LOX1, HIGH);
  digitalWrite(SHT_LOX2, LOW);
  delay(10);

  if (!lox1.begin(LOX1_ADDRESS)) {
    while (1); 
  }

  // Wake ToF 2
  digitalWrite(SHT_LOX2, HIGH);
  delay(10);

  if (!lox2.begin(LOX2_ADDRESS)) {
    while (1); 
  }
  
  delay(1000); 
}

void loop() {
  // --- 1. Read ToF Sensors ---
  VL53L0X_RangingMeasurementData_t measure1;
  VL53L0X_RangingMeasurementData_t measure2;

  lox1.rangingTest(&measure1, false);
  lox2.rangingTest(&measure2, false);

  int filtered1 = 0;
  if (measure1.RangeStatus != 4) {
    filtered1 = getMedian(measure1.RangeMilliMeter, buffer1, index1);
  }

  int filtered2 = 0;
  if (measure2.RangeStatus != 4) {
    filtered2 = getMedian(measure2.RangeMilliMeter, buffer2, index2);
  }

  // --- 2. Read MPU Sensors ---
  float raw_mpu1_Z = readMPU_Z(MPU1_ADDR);
  float raw_mpu2_Z = readMPU_Z(MPU2_ADDR);

  // Apply calibration offsets (Tweak these if the baseline ever shifts from 9.81)
  float mpu1_Z = raw_mpu1_Z - 1.49; 
  float mpu2_Z = raw_mpu2_Z - 0.79; 

  // --- 3. Plotter Formatting ---
  static bool labelsPrinted = false;
  if (!labelsPrinted) {
    // This tells the plotter what to name the lines
    Serial.println(F("ToF_1,ToF_2,MPU_1_Z,MPU_2_Z"));
    labelsPrinted = true;
  }

  // Print comma-separated values
  Serial.print(filtered1);
  Serial.print(",");
  Serial.print(filtered2);
  Serial.print(",");
  Serial.print(mpu1_Z);
  Serial.print(",");
  Serial.println(mpu2_Z); // The last one must be println!
  
  delay(40); // Matches the 25Hz rate from our Simulink test
}

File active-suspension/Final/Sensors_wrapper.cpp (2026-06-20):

/*
 * Include Files
 *
 */
#if defined(MATLAB_MEX_FILE)
#include "tmwtypes.h"
#include "simstruc_types.h"
#else
#define SIMPLIFIED_RTWTYPES_COMPATIBILITY
#include "rtwtypes.h"
#undef SIMPLIFIED_RTWTYPES_COMPATIBILITY
#endif



/* %%%-SFUNWIZ_wrapper_includes_Changes_BEGIN --- EDIT HERE TO _END */
#ifndef MATLAB_MEX_FILE
#include <Arduino.h>
#include <Wire.h>
#include <math.h>
#include "Adafruit_VL53L0X.h"

#define LOX1_ADDRESS 0x30
#define LOX2_ADDRESS 0x31
#define MPU1_ADDRESS 0x68
#define MPU2_ADDRESS 0x69

#define SHT_LOX1 25
#define SHT_LOX2 26

#define I2C_SDA 21
#define I2C_SCL 22

static Adafruit_VL53L0X lox1;
static Adafruit_VL53L0X lox2;

static volatile int32_t g_dist1_mm = -1;
static volatile int32_t g_dist2_mm = -1;
static volatile int16_t g_az1 = 0;
static volatile int16_t g_az2 = 0;
static volatile uint32_t g_tof_update_us = 0;
static volatile bool g_lox1_ok = false;
static volatile bool g_lox2_ok = false;

static float g_mpu1_z_offset = 0.0f;
static float g_mpu2_z_offset = 0.0f;

static portMUX_TYPE g_dataMux = portMUX_INITIALIZER_UNLOCKED;

static SemaphoreHandle_t g_i2cMutex = NULL;

/* ====================== MULTI-RATE KALMAN FILTER ====================== */

#define KF_N 4
#define KF_DT 0.002f

static const float KF_Ad[4][4] = {
    { 0.99761590f, 0.00234440f, 0.00184453f, -0.00181533f},
    { 0.00168796f, 0.99761766f, 0.00011007f, 0.00186025f},
    {-0.67758326f, -0.05616000f, 0.95557716f, 0.04372328f},
    { 1.63379252f, -2.32531627f, 0.10712204f, 0.86310153f}
};

static const float KF_Bd[4] = {
    0.00000265f, -0.00000188f, 0.00075287f, -0.00181533f
};


static const float KF_C[4][4] = {
    { 1.000000f, 0.000000f, 0.000000f, 0.000000f},
    { 0.000000f, 1.000000f, 0.000000f, 0.000000f},
    {-367.346939f, 0.000000f, -23.706122f, 23.706122f},
    { 900.000000f, -1250.000000f, 58.080000f, -72.806000f}
};

static const float KF_D[4] = {
    0.000000f, 0.000000f, 0.408163f, -1.000000f
};

static float KF_Q[4][4] = {
    {1e-6f, 0, 0, 0},
    { 0, 1e-4f, 0, 0},
    { 0, 0, 1e-4f, 0},
    { 0, 0, 0, 1e-3f}
};

static float KF_R_tof[2][2] = { {1e-3f, 0}, {0, 1e-3f} };
static float KF_R_mpu[2][2] = { {0.01f, 0}, {0, 0.01f} };

static float g_kf_x[4] = {0.0f, 0.0f, 0.0f, 0.0f};
static float g_kf_P[4][4];
static volatile float g_control_force_N = 0.0f;
static portMUX_TYPE g_kfMux = portMUX_INITIALIZER_UNLOCKED;

static int32_t g_prev_dist1_mm = -1;
static int32_t g_prev_dist2_mm = -1;

/* ====================== I2C HELPERS ====================== */

static inline bool I2C_Lock(TickType_t timeoutTicks) {
    if (!g_i2cMutex) return true;
    return (xSemaphoreTake(g_i2cMutex, timeoutTicks) == pdTRUE);
}

static inline void I2C_Unlock() {
    if (g_i2cMutex) xSemaphoreGive(g_i2cMutex);
}

static inline void i2cWriteByte(uint8_t addr, uint8_t reg, uint8_t val) {
    Wire.beginTransmission(addr);
    Wire.write(reg);
    Wire.write(val);
    Wire.endTransmission(true);
}

static inline bool i2cReadBytes(uint8_t addr, uint8_t startReg, uint8_t *buf, size_t len) {
    Wire.beginTransmission(addr);
    Wire.write(startReg);
    if (Wire.endTransmission(false) != 0) return false;
    int got = Wire.requestFrom((int)addr, (int)len, (int)true);
    if (got != (int)len) return false;
    for (size_t i = 0; i < len; i++) buf[i] = Wire.read();
    return true;
}

static inline void wakeUpMPU(uint8_t address) {
    i2cWriteByte(address, 0x6B, 0x00);
}

static inline void configMPU6050(uint8_t address) {
    wakeUpMPU(address);
    delay(2);
    i2cWriteByte(address, 0x1A, 0x03);
    i2cWriteByte(address, 0x19, 0x04);
    i2cWriteByte(address, 0x1C, 0x00);
    i2cWriteByte(address, 0x1B, 0x00);
}

static inline bool readMPUAccelXYZ(uint8_t address, int16_t &ax, int16_t &ay, int16_t &az) {
    uint8_t buf[6];
    if (!i2cReadBytes(address, 0x3B, buf, 6)) return false;
    ax = (int16_t)((buf[0] << 8) | buf[1]);
    ay = (int16_t)((buf[2] << 8) | buf[3]);
    az = (int16_t)((buf[4] << 8) | buf[5]);
    return true;
}

static void setVL53IDs() {
    digitalWrite(SHT_LOX1, LOW);
    digitalWrite(SHT_LOX2, LOW);
    delay(20);
    digitalWrite(SHT_LOX1, HIGH);
    digitalWrite(SHT_LOX2, HIGH);
    delay(20);
    digitalWrite(SHT_LOX1, HIGH);
    digitalWrite(SHT_LOX2, LOW);
    delay(50);

    if (I2C_Lock(pdMS_TO_TICKS(50))) {
        g_lox1_ok = lox1.begin(LOX1_ADDRESS, false);

        if (g_lox1_ok) {
            lox1.setMeasurementTimingBudgetMicroSeconds(20000);
            lox1.startRangeContinuous();
        }

        I2C_Unlock();
    }

    delay(20);
    digitalWrite(SHT_LOX2, HIGH);
    delay(50);

    if (I2C_Lock(pdMS_TO_TICKS(50))) {
        g_lox2_ok = lox2.begin(LOX2_ADDRESS, false);

        if (g_lox2_ok) {
            lox2.setMeasurementTimingBudgetMicroSeconds(20000);
            lox2.startRangeContinuous();
        }

        I2C_Unlock();
    }

}





static volatile int32_t g_consecutive_errors = 0;

static void recoverI2CBus() {
    Wire.end();
    pinMode(I2C_SCL, OUTPUT);
    pinMode(I2C_SDA, INPUT_PULLUP);

    for (int i = 0; i < 9; i++) {
        digitalWrite(I2C_SCL, LOW);
        delayMicroseconds(5);
        digitalWrite(I2C_SCL, HIGH);
        delayMicroseconds(5);
    }
    Wire.begin(I2C_SDA, I2C_SCL);
    Wire.setTimeout(150);
    Wire.setClock(400000);
}

/* ====================== KALMAN FILTER MATH ====================== */

static void kf_matmul_A_P_At(float out[4][4], const float A[4][4], const float P[4][4]) {
    float AP[4][4] = {0};
    int i, j;

    for (i=0; i<4; i++) for (j=0; j<4; j++) {
        AP[i][j] = A[i][0]*P[0][j] + A[i][1]*P[1][j] + A[i][2]*P[2][j] + A[i][3]*P[3][j];
    }

    for (i=0; i<4; i++) for (j=0; j<4; j++) {
        out[i][j] = AP[i][0]*A[j][0] + AP[i][1]*A[j][1] + AP[i][2]*A[j][2] + AP[i][3]*A[j][3];
    }
}
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

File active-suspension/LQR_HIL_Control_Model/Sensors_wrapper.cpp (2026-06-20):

/*
 * Include Files
 *
 */
#if defined(MATLAB_MEX_FILE)
#include "tmwtypes.h"
#include "simstruc_types.h"
#else
#define SIMPLIFIED_RTWTYPES_COMPATIBILITY
#include "rtwtypes.h"
#undef SIMPLIFIED_RTWTYPES_COMPATIBILITY
#endif



/* %%%-SFUNWIZ_wrapper_includes_Changes_BEGIN --- EDIT HERE TO _END */
#ifndef MATLAB_MEX_FILE
#include <Arduino.h>
#include <Wire.h>
#include "Adafruit_VL53L0X.h"
 
// -------------------- Addresses --------------------
#define LOX1_ADDRESS 0x30
#define LOX2_ADDRESS 0x31
#define MPU1_ADDRESS 0x68   // AD0=GND
#define MPU2_ADDRESS 0x69   // AD0=3.3V
 
// -------------------- Shutdown Pins ----------------
#define SHT_LOX1 25
#define SHT_LOX2 26
 
// -------------------- I2C pins ---------------------
#define I2C_SDA 21
#define I2C_SCL 22
 
// -------------------- Objects ----------------------
static Adafruit_VL53L0X lox1;
static Adafruit_VL53L0X lox2;
 
// -------------------- Shared data (ToF) ------------
static volatile int32_t  g_dist1_mm    = -1;
static volatile int32_t  g_dist2_mm    = -1;
static volatile uint32_t g_tof_update_us = 0;   
static volatile bool     g_lox1_ok     = false;
static volatile bool     g_lox2_ok     = false;

// -------------------- Dynamic Calibration ----------
static float g_mpu1_z_offset = 0.0f;
static float g_mpu2_z_offset = 0.0f;
 
// Critical section for shared variables
static portMUX_TYPE      g_dataMux     = portMUX_INITIALIZER_UNLOCKED;
static SemaphoreHandle_t g_i2cMutex    = NULL;
 
// -------------------- Helpers ----------------------
static inline bool I2C_Lock(TickType_t timeoutTicks) {
  if (!g_i2cMutex) return true;
  return (xSemaphoreTake(g_i2cMutex, timeoutTicks) == pdTRUE);
}
 
static inline void I2C_Unlock() {
  if (g_i2cMutex) xSemaphoreGive(g_i2cMutex);
}
 
static inline void i2cWriteByte(uint8_t addr, uint8_t reg, uint8_t val) {
  Wire.beginTransmission(addr);
  Wire.write(reg);
  Wire.write(val);
  Wire.endTransmission(true);
}
 
static inline bool i2cReadBytes(uint8_t addr, uint8_t startReg, uint8_t *buf, size_t len) {
  Wire.beginTransmission(addr);
  Wire.write(startReg);
  if (Wire.endTransmission(false) != 0) return false;
  int got = Wire.requestFrom((int)addr, (int)len, (int)true);
  if (got != (int)len) return false;
  for (size_t i = 0; i < len; i++) buf[i] = Wire.read();
  return true;
}
 
static inline void wakeUpMPU(uint8_t address) {
  i2cWriteByte(address, 0x6B, 0x00);
}
 
static inline void configMPU6050(uint8_t address) {
  wakeUpMPU(address);
  delay(2);
  // DLPF set to 44Hz (0x03) to filter high-frequency mechanical noise
  i2cWriteByte(address, 0x1A, 0x03);
  i2cWriteByte(address, 0x19, 0x04);
  i2cWriteByte(address, 0x1C, 0x00);  // +/- 2g  -> divide by 16384.0 in Simulink
  i2cWriteByte(address, 0x1B, 0x00);
}
 
static inline bool readMPUAccelXYZ(uint8_t address, int16_t &ax, int16_t &ay, int16_t &az) {
  uint8_t buf[6];
  if (!i2cReadBytes(address, 0x3B, buf, 6)) return false;
  ax = (int16_t)((buf[0] << 8) | buf[1]);
  ay = (int16_t)((buf[2] << 8) | buf[3]);
  az = (int16_t)((buf[4] << 8) | buf[5]);
  return true;
}
 
// -------------------- 5-Point Median Filter --------
static inline int32_t getMedian(int32_t newValue, int32_t *buffer, uint8_t &index) {
  buffer[index] = newValue;
  index = (index + 1) % 5;
  int32_t temp[5];
  for (int i = 0; i < 5; i++) temp[i] = buffer[i];
  for (int i = 0; i < 4; i++) {
    for (int j = 0; j < 4 - i; j++) {
      if (temp[j] > temp[j + 1]) {
        int32_t swap = temp[j];
        temp[j]     = temp[j + 1];
        temp[j + 1] = swap;
      }
    }
  }
  return temp[2];
}
 
// ------------- VL53L0X address assignment -----------
static void setVL53IDs() {
  digitalWrite(SHT_LOX1, LOW);
  digitalWrite(SHT_LOX2, LOW);
  delay(20);
 
  digitalWrite(SHT_LOX1, HIGH);
  digitalWrite(SHT_LOX2, HIGH);
  delay(20);
 
  digitalWrite(SHT_LOX1, HIGH);
  digitalWrite(SHT_LOX2, LOW);
  delay(50);
 
  if (I2C_Lock(pdMS_TO_TICKS(50))) {
    g_lox1_ok = lox1.begin(LOX1_ADDRESS, false);
    if (g_lox1_ok) {
      lox1.setMeasurementTimingBudgetMicroSeconds(20000);
      lox1.startRangeContinuous();
    }
    I2C_Unlock();
  } else {
    g_lox1_ok = false;
  }
  delay(20);
 
  digitalWrite(SHT_LOX2, HIGH);
  delay(50);
 
  if (I2C_Lock(pdMS_TO_TICKS(50))) {
    g_lox2_ok = lox2.begin(LOX2_ADDRESS, false);
    if (g_lox2_ok) {
      lox2.setMeasurementTimingBudgetMicroSeconds(20000);
      lox2.startRangeContinuous();
    }
    I2C_Unlock();
  } else {
    g_lox2_ok = false;
  }
  delay(20);
}
 
// ------------- ToF background task ------------------
static void ToFTask(void *param) {
  const TickType_t period = pdMS_TO_TICKS(40);
  TickType_t lastWake = xTaskGetTickCount();
 
  int32_t buffer1[5], buffer2[5];
  uint8_t index1 = 0, index2 = 0;
 
  int32_t seed1 = 200, seed2 = 200;  
  if (I2C_Lock(pdMS_TO_TICKS(100))) {
    if (g_lox1_ok) {
      for (int attempt = 0; attempt < 5; attempt++) {
        if (lox1.isRangeComplete()) {
          int32_t r = lox1.readRange();
          if (r > 0 && r < 8000) { seed1 = r; break; }
        }
        delay(25);
      }
    }
    if (g_lox2_ok) {
      for (int attempt = 0; attempt < 5; attempt++) {
        if (lox2.isRangeComplete()) {
          int32_t r = lox2.readRange();
          if (r > 0 && r < 8000) { seed2 = r; break; }
        }
        delay(25);
      }
    }
    I2C_Unlock();
  }
  for (int i = 0; i < 5; i++) { buffer1[i] = seed1; buffer2[i] = seed2; }
 
  float ema1 = (float)seed1;
  float ema2 = (float)seed2;
  const float alpha = 0.25f;
 
  for (;;) {
    vTaskDelayUntil(&lastWake, period);
 
    if (I2C_Lock(pdMS_TO_TICKS(10))) {
 
      if (g_lox1_ok && lox1.isRangeComplete()) {
        int32_t d1 = lox1.readRange();
        if (d1 > 0 && d1 < 8000) {
          int32_t med1 = getMedian(d1, buffer1, index1);
          ema1 = alpha * (float)med1 + (1.0f - alpha) * ema1;
          portENTER_CRITICAL(&g_dataMux);
          g_dist1_mm      = (int32_t)(ema1 + 0.5f);
          g_tof_update_us = micros();   
          portEXIT_CRITICAL(&g_dataMux);
        }
      }
 
      if (g_lox2_ok && lox2.isRangeComplete()) {
        int32_t d2 = lox2.readRange();
        if (d2 > 0 && d2 < 8000) {
          int32_t med2 = getMedian(d2, buffer2, index2);
          ema2 = alpha * (float)med2 + (1.0f - alpha) * ema2;
          portENTER_CRITICAL(&g_dataMux);
          g_dist2_mm = (int32_t)(ema2 + 0.5f);
          portEXIT_CRITICAL(&g_dataMux);
        }
      }
 
      I2C_Unlock();
    }
  }
}
#endif
/* %%%-SFUNWIZ_wrapper_includes_Changes_END --- EDIT HERE TO _BEGIN */
#define y_width 1
#define y_1_width 1
#define y_2_width 1
#define y_3_width 1

/*
 * Create external references here.  
 *
 */
/* %%%-SFUNWIZ_wrapper_externs_Changes_BEGIN --- EDIT HERE TO _END */
/* extern double func(double a); */
/* %%%-SFUNWIZ_wrapper_externs_Changes_END --- EDIT HERE TO _BEGIN */

/*
 * Start function
 *
 */
extern "C" void Sensors_Start_wrapper(void);
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

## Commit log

2026-04-12 adding all files
    [ACTIVESUSPENSIONSYS.SLDASM, ACTIVESUSPENSIONSYSTEM.SLDASM, ACTIVESUSPENSIONSYS_OPT.SLDASM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]
2026-06-13 cloud files added
    [ACTIVESUSPENSIONSYS.SLDASM, ACTIVESUSPENSIONSYSTEM.SLDASM, ACTIVESUSPENSIONSYS_OPT.SLDASM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]
2026-06-20 AEKF Added
    [session_data.csv]
2026-07-05 Restructure repo into active-suspension/ subfolder
    Making room to merge the CoTune Rotary Pendulum and Web/Cloud
    components into this repo alongside the existing active suspension
    work, ahead of renaming this repo to CoTune Remote Control Lab.
    [ACTIVESUSPENSIONSYS.SLDASM, ACTIVESUSPENSIONSYSTEM.SLDASM, ACTIVESUSPENSIONSYS_OPT.SLDASM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]
2026-07-05 Remove stale root-level paths left over from the active-suspension/ move
    A git reset between staging the move and committing it left the old
    paths tracked in the index alongside the new active-suspension/ copies.
    [ACTIVESUSPENSIONSYS.SLDASM, ACTIVESUSPENSIONSYSTEM.SLDASM, ACTIVESUSPENSIONSYS_OPT.SLDASM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]
2026-07-05 Add web-cloud dashboard
    Snapshot of the React/AWS front end and cloud infrastructure (IoT
    Core, Cognito, DynamoDB, Amplify) that puts the active suspension and
    rotary pendulum experiments online, folded in as part of CoTune as a
    whole. Excludes the .env secret, node_modules/build artifacts, and the
    amplify/team-provider-info.json file (which exposed a real AWS account
    ID and role ARNs).
    [2dofhover.urdf, Active_Suspension_urdf.csv, Active_Suspension_urdf.urdf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]
